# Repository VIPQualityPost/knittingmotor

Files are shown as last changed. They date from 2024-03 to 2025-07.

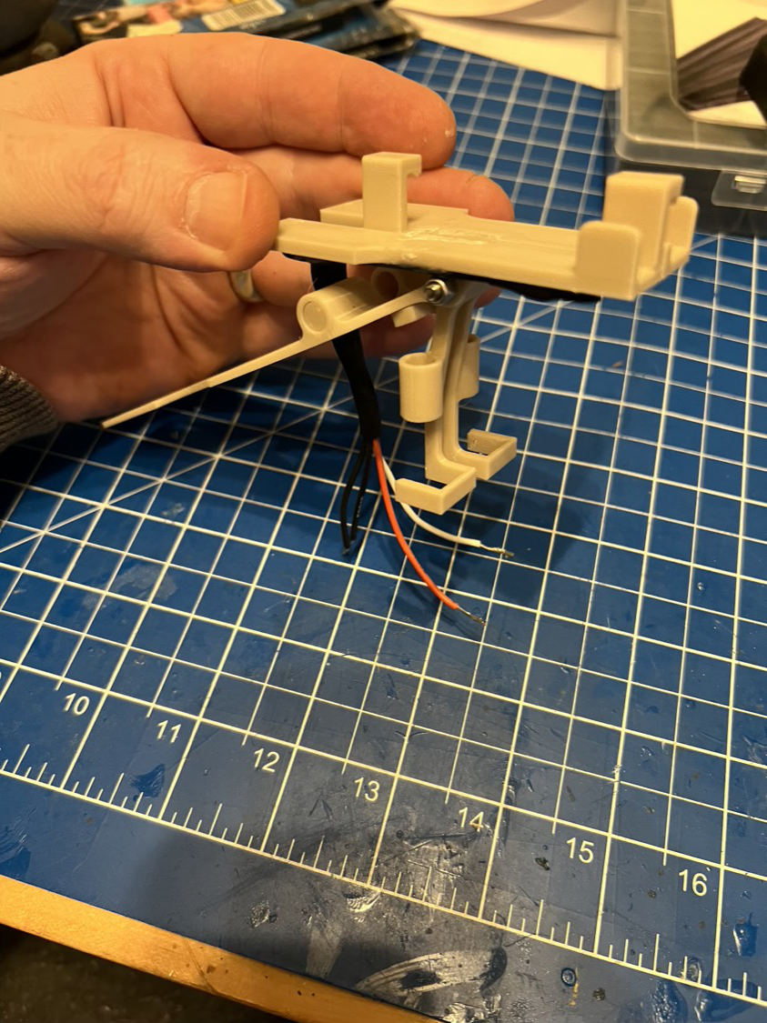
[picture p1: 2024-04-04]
docs/content/rl/pictures/yarn_sensor_build_4.jpg

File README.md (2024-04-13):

# OKM - Open Knitting Motor project
===================================

THIS PROJECT AND ITS DOCUMENTATION IS WORK IN PROGRESS - EVEN THOUGH THE ACTUAL MACHINE WORKS, THERE ARE STILL SOME DOCUMENTATIONAL PARTS MISSING, SO IT MIGHT NOT BE AS EASY TO FOLLOW EVERYTHING AS IT SHOULD!

This project intends to provide a knitting motor for the common Brother flat bed knitting machines. It is originally build for a Brother KH 830 knitting machine, but the parts can be customized easily, so that it can be used with different machines.

It provides currently the following features:

*Features:*
- manual knitting with simple row counter
- automatic knitting a pre-defined no. of rows
- foot pedal control (single row / continuous knitting)
- knitting of the whole bed or a subsection
- setup and row data saved between power on/off
- alarm song after pre-defined no. of rows done
- user definable speed setting

*Machine operation and safety features:*
- high resolution stepper motor driver
- electronic endstops and carriage transport overload protection
- mechanic (spring driven) carriage coupler (additionally to overload protection)
- yarn and knot sensor (optional)

Current documentation: https://pages.open-mind.space/knittingmotor

Firmware release overview: https://gitlab.open-mind.space/pages/knittingmotor/-/releases

Building this device is not for the faint-hearted, because you will have to solder, crimp connectors, even deal with mains connections (! PLEASE BE CAREFUL ! I AM NOT RESPONSIBLE IF SOMETHING GOES WRONG HERE !), building and uploading the firmware to the Arduino, and in the end, debug the whole thing if something does not work as expected.

So, if you are not familiar with doing things like this, please ask a friend with appropriate skills for help.

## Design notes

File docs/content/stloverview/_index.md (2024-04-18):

---
title: "STL overview"
date:  "2024-04-07"
weight: 40
---

------

{{< figure src="/knittingmotor/images/CAD_OKM.png" link="/knittingmotor/images/CAD_OKM.png" target="blank" title="(click to zoom)" height="60%" width="60%" >}}

------

This overview is just for informational purpose.

Download the current STL files or the combined 3MF from: [source files](https://gitlab.open-mind.space/pages/knittingmotor)

<br>

{{< gallery match="pictures/*" sortOrder="desc" rowHeight="150" margins="5" thumbnailResizeOptions="600x600 q90 Lanczos" showExif=true previewType="blur" embedPreview=true loadJQuery=true >}}

---

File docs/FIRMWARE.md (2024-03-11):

# Open Knitting Motor - Firmware

The project is being developed under Visual Studio Code with the PlatformIO plugin. If you use the same IDE, you should not have any problems compiling and flashing the firmware to the Arduino, as all necessary external libraries will be configured via `platformio.ini`.

## Choosing the right firmware branch

The firmware comes in two different versions:
- Arduino R3 support (`master` branch)
- Arduino R4 support (`r4wifiv2` branch)

Choose the firmware branch according the Arduino UNO type you are using. The branches are not cross-compatible, so you cannot simply compile the `master` branch and use it wth the Arduino R4. This simply won't work.

## Multi-language support
The firmware comes in two different languages at the moment, German or English. You can change this in `platform.io`via the `build_flags` parameter:

- -D LANG_DE (for German) <br>
or <br>
- -D LANG_EN (for English)

I did not build a live language option into the firmware, as it won't happen too often that a user wants to change the language while using the machine. So, the language will be compiled directly into the firmware.

If you want to add another language, see `Lang.h` for how it is done.

## Serial debug options
If you want to enable some more (serial) DEBUG options, you can setup some additional `build_flags` in platformio.ini:

- -D DEBUG: will enable general debug output, has to be defined always for debuggin
- -D DEBUG_APPMODE: will generate debug messages regarding the firmware operation itself
- -D DEBUG_POSITION: will generate additional information regarding the stepper and encoder operation

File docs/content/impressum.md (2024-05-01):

---
title: "Impressum/Imprint"
date: 2024-04-05
lastmod: 2024-04-05
publishdate: 2024-04-05
description: ""
weight: 1000
---

<div class='impressum'><h1>Impressum</h1><p>Angaben gemäß § 5 TMG</p><p>Holger Pandel <br> 
Am Steinbrink 15<br> 
47447 Moers <br> 
</p><p> <strong>Vertreten durch: </strong><br>
Holger Pandel<br>
</p><p><strong>Kontakt:</strong> <br>
Telefon: 02841-9393211<br>
E-Mail: <a href='mailto:holger.pandel@googlemail.com'>holger.pandel@googlemail.com</a></br></p><p><strong>Haftungsausschluss: </strong><br><br><strong>Haftung für Inhalte</strong><br><br>
Die Inhalte unserer Seiten wurden mit größter Sorgfalt erstellt. Für die Richtigkeit, Vollständigkeit und Aktualität der Inhalte können wir jedoch keine Gewähr übernehmen. Als Diensteanbieter sind wir gemäß § 7 Abs.1 TMG für eigene Inhalte auf diesen Seiten nach den allgemeinen Gesetzen verantwortlich. Nach §§ 8 bis 10 TMG sind wir als Diensteanbieter jedoch nicht verpflichtet, übermittelte oder gespeicherte fremde Informationen zu überwachen oder nach Umständen zu forschen, die auf eine rechtswidrige Tätigkeit hinweisen. Verpflichtungen zur Entfernung oder Sperrung der Nutzung von Informationen nach den allgemeinen Gesetzen bleiben hiervon unberührt. Eine diesbezügliche Haftung ist jedoch erst ab dem Zeitpunkt der Kenntnis einer konkreten Rechtsverletzung möglich. Bei Bekanntwerden von entsprechenden Rechtsverletzungen werden wir diese Inhalte umgehend entfernen.<br><br><strong>Haftung für Links</strong><br><br>
Unser Angebot enthält Links zu externen Webseiten Dritter, auf deren Inhalte wir keinen Einfluss haben. Deshalb können wir für diese fremden Inhalte auch keine Gewähr übernehmen. Für die Inhalte der verlinkten Seiten ist stets der jeweilige Anbieter oder Betreiber der Seiten verantwortlich. Die verlinkten Seiten wurden zum Zeitpunkt der Verlinkung auf mögliche Rechtsverstöße überprüft. Rechtswidrige Inhalte waren zum Zeitpunkt der Verlinkung nicht erkennbar. Eine permanente inhaltliche Kontrolle der verlinkten Seiten ist jedoch ohne konkrete Anhaltspunkte einer Rechtsverletzung nicht zumutbar. Bei Bekanntwerden von Rechtsverletzungen werden wir derartige Links umgehend entfernen.<br><br><strong>Urheberrecht</strong><br><br>
Die durch die Seitenbetreiber erstellten Inhalte und Werke auf diesen Seiten unterliegen dem deutschen Urheberrecht. Die Vervielfältigung, Bearbeitung, Verbreitung und jede Art der Verwertung außerhalb der Grenzen des Urheberrechtes bedürfen der schriftlichen Zustimmung des jeweiligen Autors bzw. Erstellers. Downloads und Kopien dieser Seite sind nur für den privaten, nicht kommerziellen Gebrauch gestattet. Soweit die Inhalte auf dieser Seite nicht vom Betreiber erstellt wurden, werden die Urheberrechte Dritter beachtet. Insbesondere werden Inhalte Dritter als solche gekennzeichnet. Sollten Sie trotzdem auf eine Urheberrechtsverletzung aufmerksam werden, bitten wir um einen entsprechenden Hinweis. Bei Bekanntwerden von Rechtsverletzungen werden wir derartige Inhalte umgehend entfernen.<br><br><strong>Datenschutz</strong><br><br>
Die Nutzung unserer Webseite ist in der Regel ohne Angabe personenbezogener Daten möglich. Soweit auf unseren Seiten personenbezogene Daten (beispielsweise Name, Anschrift oder eMail-Adressen) erhoben werden, erfolgt dies, soweit möglich, stets auf freiwilliger Basis. Diese Daten werden ohne Ihre ausdrückliche Zustimmung nicht an Dritte weitergegeben. <br>
Wir weisen darauf hin, dass die Datenübertragung im Internet (z.B. bei der Kommunikation per E-Mail) Sicherheitslücken aufweisen kann. Ein lückenloser Schutz der Daten vor dem Zugriff durch Dritte ist nicht möglich. <br>
Der Nutzung von im Rahmen der Impressumspflicht veröffentlichten Kontaktdaten durch Dritte zur Übersendung von nicht ausdrücklich angeforderter Werbung und Informationsmaterialien wird hiermit ausdrücklich widersprochen. Die Betreiber der Seiten behalten sich ausdrücklich rechtliche Schritte im Falle der unverlangten Zusendung von Werbeinformationen, etwa durch Spam-Mails, vor.<br>
<br>
Impressum vom <a href="https://www.impressum-generator.de">Impressum Generator</a> der <a href="https://www.kanzlei-hasselbach.de/standorte/frankfurt/">Kanzlei Hasselbach, Frankfurt</a> </div>

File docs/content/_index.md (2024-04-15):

---
title: "_Index"
date: 2024-03-18T11:07:29+01:00
lastmod: 2024-03-18T11:07:29+01:00
publishdate: 2024-03-18T11:07:29+01:00
description: ""
weight: 10
---

Welcome to my

# Open Knitting Motor Project

------
| {{< figure src="/knittingmotor/images/CAD_OKM.png" link="/knittingmotor/images/CAD_OKM.png" target="blank" title="(click to zoom)" height="80%" width="80%" >}} | {{< figure src="/knittingmotor/images/CAD_OKM_back.png" link="/knittingmotor/images/CAD_OKM_back.png" target="blank" title="(click to zoom)" height="80%" width="80%" >}} |
| :---: | :---: |
------

Here you find every information you need to build and use your own custom flatbed knitting machine motor.

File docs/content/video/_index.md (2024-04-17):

---
title: "Introduction video"
date: "2024-04-12"
weight: 10
TableOfContents: false
---

The following video should give you a comprehensive introduction to my open knitting motor. There are more videos to come, especially those explaining the different features you can setup within the control box.

---
<br>
{{< youtube DNebWPWqzuI >}}

[Follow this link to the complete Youtube playlist with all videos regarding the system!](https://www.youtube.com/playlist?list=PLf4mh2tju_ITPJRGPDabReALq2cNbygUf)

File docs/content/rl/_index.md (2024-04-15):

---
title: "Pictures from the build"
date:  "2024-04-04"
weight: 30
---

---

{{< figure src="/knittingmotor/images/OKM_build_view.jpg" link="/knittingmotor/images/OKM_build_view.jpg" target="blank" title="(click to zoom)" height="60%" width="60%" >}}

---

## So, what do you think?

No worries, I can assure you, it is working as of now. Here you find a bunch of pictures I took during the build of the actual machine itself. I hope, you find them useful in the process of building your own motor.

<br>

{{< gallery match="pictures/*" sortOrder="desc" rowHeight="150" margins="5" thumbnailResizeOptions="600x600 q90 Lanczos" showExif=true previewType="blur" embedPreview=true loadJQuery=true >}}

---

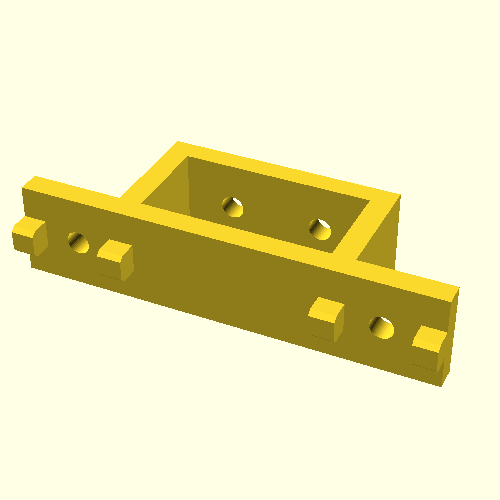
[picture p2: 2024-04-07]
docs/content/stloverview/pictures/frame_barclamp_(2x).stl.png

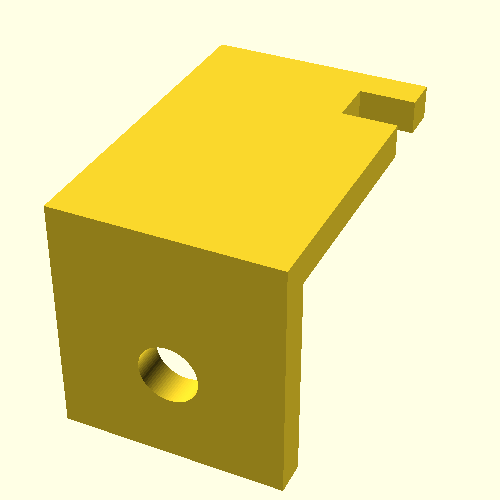
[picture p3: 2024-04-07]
docs/content/stloverview/pictures/frame_main_clamp_left.stl.png

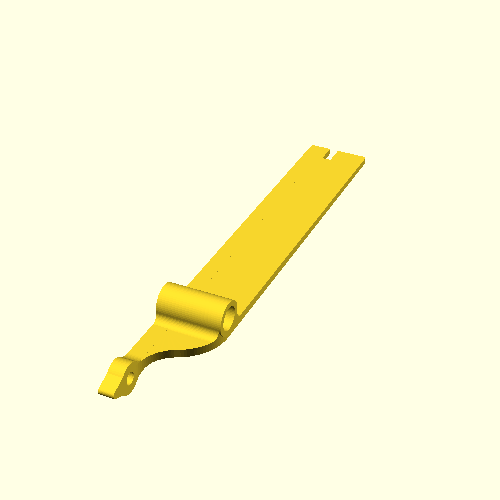
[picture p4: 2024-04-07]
docs/content/stloverview/pictures/yarn_sensor_knot_main_thread.stl.png

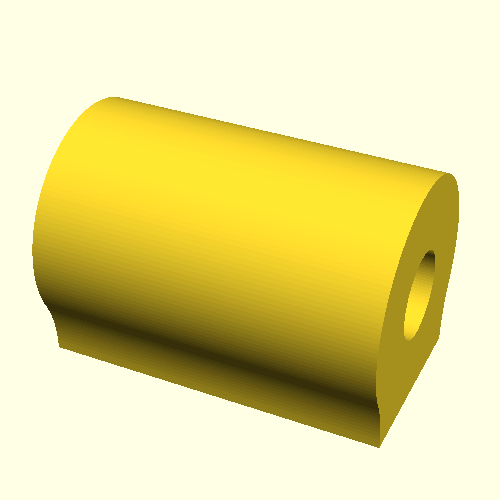
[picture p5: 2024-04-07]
docs/content/stloverview/pictures/belt_tensioner_pusher.stl.png

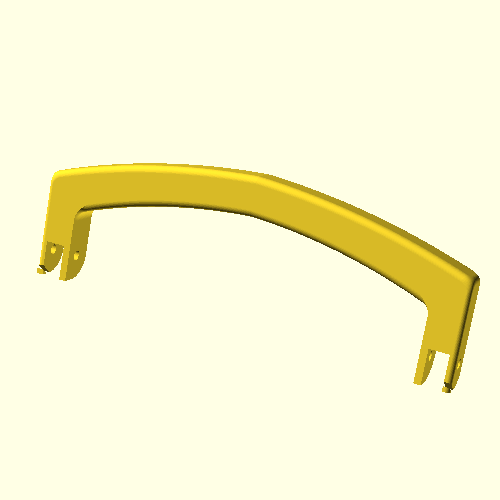
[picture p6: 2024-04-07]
docs/content/stloverview/pictures/carriage_handle_bar.stl.png

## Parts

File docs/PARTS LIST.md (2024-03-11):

# Open Knitting Motor - Parts list

This document hopefully lists all the needed parts to build the open knitting motor.

## 3D printed parts

Print all of the parts you find in the `Kitting machine motor.3mf`. I used 6 walls, with 35% infill at 0.2mm layer height and tree support where needed. If you have a Bambulab X1C printer, you should be able to use the 3MF file directly without any further modifications.

Regarding the housing, you have to choose between TB6600 and DM542T because of the stepper driver.

## V-Slot Extrusions and accessories

- 2020:
  - 1700mm (1x)
  - 1160mm (1x)

- 2040:
  - 250mm (2x)
  - 200mm (2x)

- corner brackets (8 minimum, more as you like)
- T-nuts (35 minimum)
- M5x8 T-nut pan head screws
- end caps for extrusions, if you like

## Electronics

- Arduino UNO R3 (R4 support since 0.4.6+78 in separate fw branch)
- DFRobot LCD Keypad shield
- LM2596 Step-down DC-DC Buck-Converter modul for 4-40V to 3,3-24V
- Passive buzzer module
- Optical rotary A/B encoder E38S6G5-600B-G24N
- DC power supply 24V 10A
- IEC320 / C14 power jack
- Nema 23 stepper motor type 23HS2430B [like this](https://www.sys-motor.com/show.aspx?id=165)
- Stepper driver alternatives (configured for 1600 steps):
    1. TB6600 stepper driver (works, but not recommended)
    2. DM542T (MUCH better, quieter, more precise, etc. etc.)
- 12V 2-pin Fan (40x40x10)
- (2x) Lerdge endstops [like this](https://shop.lerdge.com/products/mechanical-endstop-horizontal)
- (2x) small endstop switches (normally closed, footswitch+overload)
- (4x) reed contact 10mm (normally closed, yarn sensing)
- (2x) GX16 4-pin male+female plug connector (for stepper motor and encoder)
- (3x-4x) Stereo jack connector socket panel mount (for endstops, footswitch, (optional) overload and yarn sensor)
- (3x-4x) 3.5mm stereo TRS plug
- something to connect all GND and +5V lines together - I used Wago splicing connectors with levers, but everthing else with which you can connect multiple wires into one should work :D

## Mechanics

- (1x) Openbuild V-slot gantry for 2020 with 4 wheels, [like this](https://openbuildspartstore.com/v-slot-gantry-kit-20mm/)
- (1x) GT2 pulley 30T 8mm bore
- (1x) GT2 idler pulley with 5mm bore
- (5m) GT2 belt 6mm width
- (1x) (heatbed) compression spring (len 20 mm/0.79 inch, od 7.5 mm/0.3 inch, id 5 mm/0.2 inch, wire 1.2 mm)
- a whole bunch of M3, M4, M5 and M6 screws in different lengths
- about 500mm 0.8 piano wire

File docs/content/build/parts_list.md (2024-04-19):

---
title: "Parts list"
date:  "2024-03-18"
#menu:
#  main:
#      parent: Build your own!
weight: 10
TableOfContents: true
---

This document hopefully lists all the needed parts to build the open knitting motor.

## 3D printed parts

If you have a Bambulab X1C printer and  use BambuStudio as your preferred slicer, print all of the parts you find in the `Open knitting motor.3mf`without any further modifications. I positioned every item the same way I printed them myself. 

If you have to use the single STL files, then, as a rule of thumb, 

- use 6 walls
- with 35% infill at 0.2mm layer height
- tree support where needed.

Regarding the housing, you have to choose between TB6600 and DM542T because of the stepper driver.

For the foot switch, get the following part from its designer *flummer* directly via Printables:
Foot switch: https://www.printables.com/de/model/723123-foot-pedal-switch

## V-Slot Extrusions and accessories

- 2020:
  - 1700mm (1x, run bar)
  - 1160mm (1x, front rest bar)

- 2040:
  - 250mm (2x, mount post)
  - 200mm (2x, foot)

- [Openbuild V-slot gantry for 2020 with 4 wheels,](https://openbuildspartstore.com/v-slot-gantry-kit-20mm/)
- [corner brackets](https://openbuildspartstore.com/cast-corner-bracket/) (8 minimum, more as you like)
- T-nuts M5 (for frame connection, about 36, but it is handy two a some more)
- M5x8 T-nut pan head screws for the T-nuts
- M3 hammer nuts (for fixing endstops, etc.)
- end caps for extrusions (for esthetical reasons, if you like)

I cannot give you any advice where to buy your parts from, but for the extrusion, see the [Openbuilds Partstore](https://openbuildspartstore.com/) for reference.

## Electronics

I try to provide links to every part as an example, so that you can see what is meant exactly.

- [Arduino UNO R4 Wifi](https://store.arduino.cc/products/uno-r4-wifi) (DON'T use UNO R3, firmware does not support it anymore)
- [D1 Robot LCD Keypad shield](https://www.aliexpress.us/item/3256805923237105.html)<br>
  There are other  shields made by DFRobot, but they are slightly different and bigger. They won't fit into the keypad bezzle and also may react differently to the buttons attached, so try to find the exact same one made by D1 Robot.
- [LM2596 Step-down DC-DC Buck-Converter modul for 4-40V to 3,3-24V](https://www.amazon.de/gp/product/B08T1ZR6XG)
- [Passive(!) Arduino buzzer module](https://www.amazon.de/gp/product/B096ZWCG7F)
- [Optical rotary A/B encoder 600P/R rotary encoder](https://www.amazon.com/Signswise-Incremental-Optical-Encoder-Quadrature/dp/B085ZLCYS1)<br>
  Its technical no. is sometimes *LPD3806-600BM-G5-24C* or *E38S6G5-600B-G24N*.
- [DC power supply 24V 10A](https://www.amazon.de/gp/product/B0896XTJ14)
- [IEC320 / C14 power jack (pre-wired at best)](https://www.amazon.com/button-Adapter-Connector-Socket-MXRS/dp/B082ZFRV1B)
- [Nema 23 stepper motor type 23HS2430B](https://www.sys-motor.com/show.aspx?id=165)
- Stepper driver alternatives (configured for 1600 steps):
    1. [TB6600 stepper driver](https://www.amazon.com/Stepper-DC9-42V-Subdivision-Controller-MicroStepping/dp/B08SG7L54W) (works, but not recommended)
    2. [DM542T stepper driver](https://www.omc-stepperonline.com/search?search=dmt542t&description=true) (MUCH MUCH better, quieter, more precise, etc. etc.)
- [Noctua 12V 3-pin fan (40x40x10)](https://www.amazon.com/Noctua-Cooling-Blades-Bearing-NF-A4x10/dp/B009NQLT0M)
- [ZHIYU 1X3L fan controller](https://www.ebay.com/itm/404706261069)
- (2x) [Lerdge endstops ](https://shop.lerdge.com/products/mechanical-endstop-horizontal)
- (2x) [small endstop switches](https://www.amazon.de/gp/product/B07P85749W) (normally closed, footswitch+overload)
- (2x) [GPS-11B reed contact 10mm](https://www.ebay.com/itm/284819532789) (normally closed, yarn knot sensor)
- (2x) [GPS-14A reed contact 14mm](https://www.ebay.com/itm/284819532789) (normally open, yarn run out sensor)
- (4x) [neodymium magnet 6mm x 3mm](https://www.ebay.com/itm/305313785899) (for reed contacts used in yarn sensor)
- (2x) [GX16 4-pin male+female plug connector](https://www.ebay.com/itm/335215956016) (for stepper motor and encoder)
- (3x-5x) [Stereo jack connector socket panel mount](https://www.ebay.com/itm/385445764175) (two endstops, footswitch, (optional) overload and yarn sensor)
- (3x-5x) [3.5mm stereo TRS plug](https://www.amazon.com/Fancasee-Replacement-Connector-Headphone-Earphone/dp/B07Y8KGJKL)
- something to connect all GND and +5V lines together - I used Wago splicing connectors with levers, but everthing else with which you can connect multiple wires into one should work :D
- A bunch of wires
    1. 24 AWG (multi-color): Arduino, rotary encoder, switches, reed contacts
    2. 18-20 AWG: power supply to step down, stepper+driver phase connections (better use 4 core cable with shielding)

## Additional mechanical parts

- **(2x) [original ribber clamps for KR830/850](https://theknittingcloset.com/products/knitting-machine-ribber-parts), you cannot use the whole setup without them**
- (1x) [GT2 pulley 30T 8mm bore](https://www.amazon.com/Saipe-Synchronous-Teeth-Bore-8mm/dp/B09JS7CZNM)
- (1x) [GT2 idler pulley 5mm bore](https://www.amazon.com/3Dman-Toothless-Aluminum-Timing-Printer/dp/B07RV2T54M)
- (5m) [GT2 belt 6mm width](https://www.amazon.com/Timing-Printer-FYSETC-Fiberglass-Reinforced/dp/B07BRKZGMS)
- (1x)  compression spring (len 20 mm/0.79 inch, od 7.5 mm/0.3 inch, id 5 mm/0.2 inch, wire 1.2 mm) - i. e. for 3D printer heatbed
- a whole bunch of M3, M4, M5 and M6 screws and (nylon lock) nuts in different lengths
- about 500mm 0.8 piano wire

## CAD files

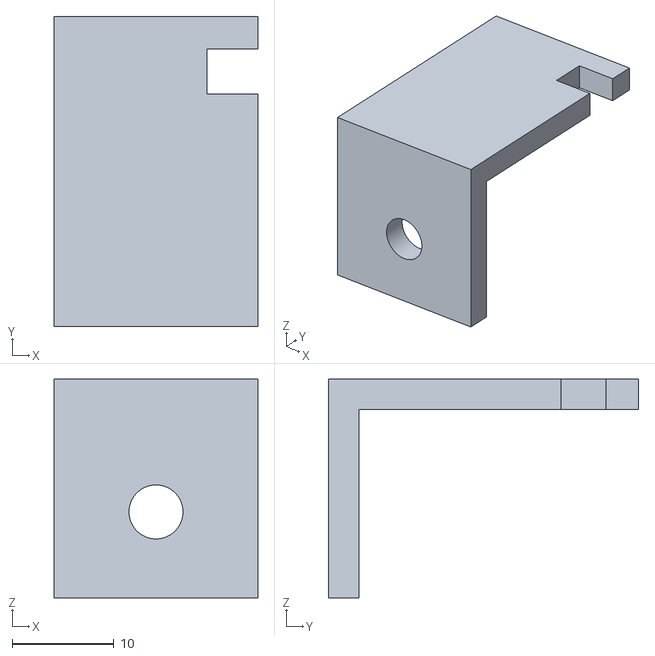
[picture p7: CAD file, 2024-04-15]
STL/frame_main_clamp_left.stl
20.0 x 30.5 x 21.5

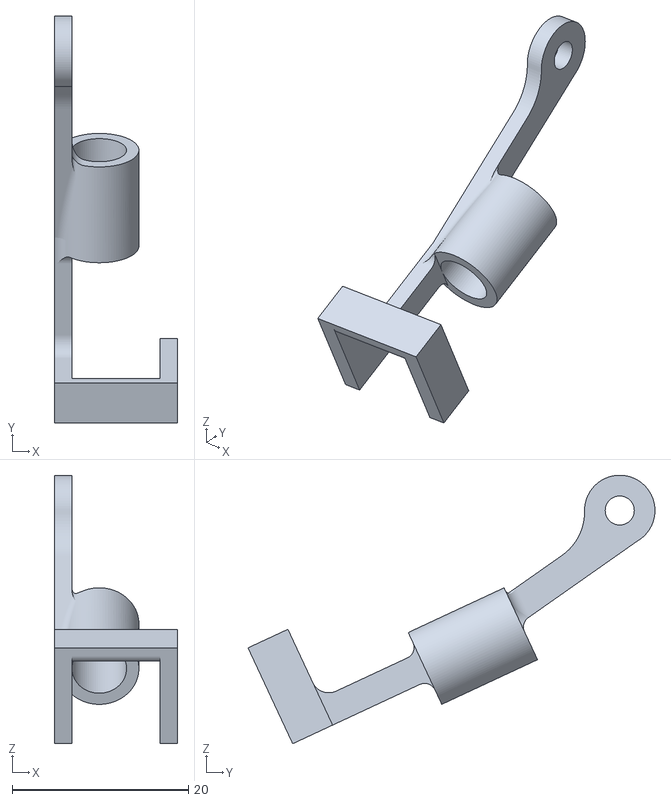
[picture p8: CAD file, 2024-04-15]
STL/yarn_sensor_main_thread.stl
14.0 x 46.2 x 30.5

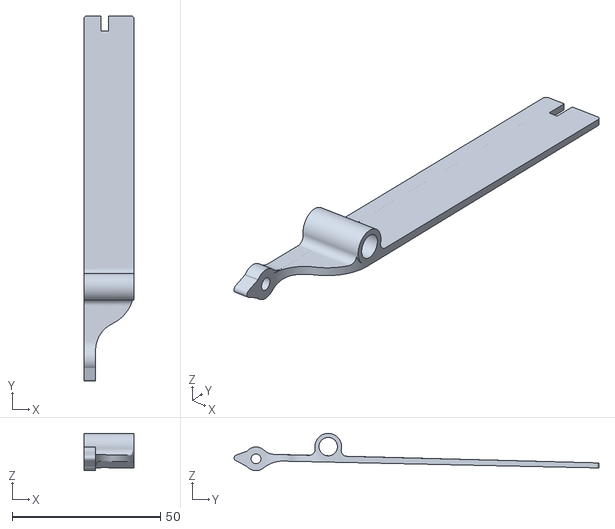
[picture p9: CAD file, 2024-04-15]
STL/yarn_sensor_knot_main_thread.stl
17.0 x 123.1 x 12.6

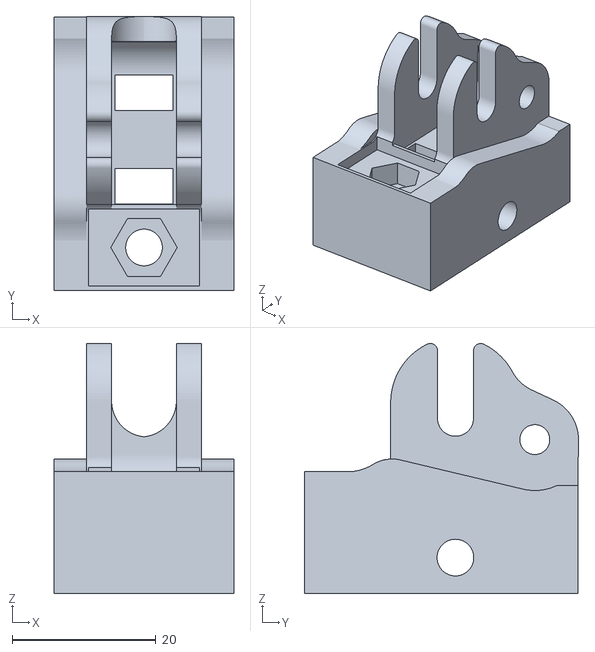
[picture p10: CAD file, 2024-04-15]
STL/belt_tensioner_main_body.stl
25.0 x 38.1 x 34.8

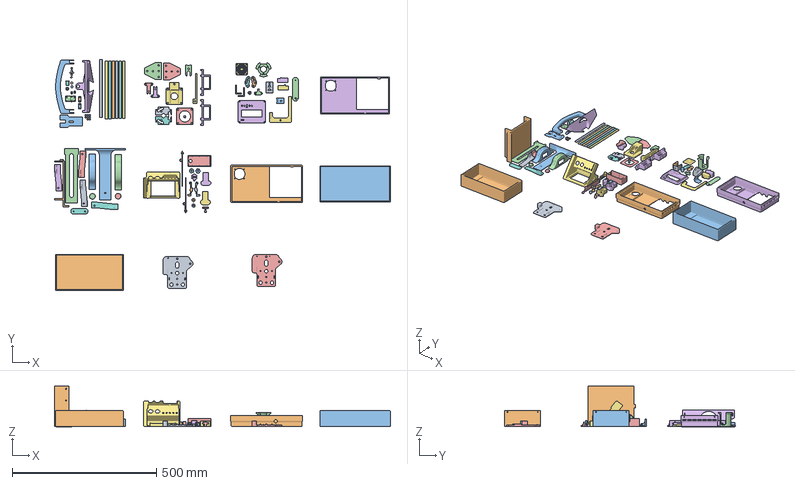
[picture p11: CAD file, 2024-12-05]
Open knitting motor.3mf
1165.1 x 800.2 x 141.9 mm
Mover plate.stl
lower housing (TB6600).stl
yarn sensor base.stl
stabilizer rod fixer.stl
yarn knot sensor main thread.stl
barclamp.stl x 2
yarn knot sensor second thread.stl
stabilizer short arm.stl
yarn sensor second thread.stl
yarn sensor main thread.stl
stabilizer mount.stl
rotary encoder bracket bridge.stl
yarn sensor base screw mount.stl
carrier adapter.stl
spring lever.stl
carrier bolt.stl
spring bolt spacer.stl
spring presser.stl x 2
carrier handle bar.stl
t-joining plate.stl x 2
Nema 23 2020 Extrusion Bracket.stl
Idler support tube.stl
main clamp right.stl
main clamp left.stl
belt slider.stl x 2
motor spacer.stl
upper housing part 1 (TB6600).stl
upper housing part 2.stl
LCD Keypad Pushbutton v3.stl x 6
LCD keypad bezzle.stl
Fan grill v2.stl
rotary encoder bracket base right.stl
rotary encoder bracket base left.stl
Flexible Shaft Coupler Sleeve 6mm.stl
Flexible Shaft Coupler Sleeve 8mm.stl
Flexible Shaft Coupler Body.stl
vertical stiffner right.stl x 2
vertical stiffner left.stl x 2
mover endstop bracket.stl
control box table.stl
control box table foot part 2.stl
control box table foot part1.stl
endstop mount.stl x 2
VslotCover_Cust_50mm.stl x 7
GT2_Clip_7_mm.stl x 2
Belt holder right.stl
Belt holder left.stl
right arm
main body
left arm
pusher
overload sensor mount.stl
pulley lid.stl
endstop lid.stl x 2
M5_std_screw_knob.stl x 2
M3_std_screw_knob.stl x 2
GX16 blind plug.stl x 2
cable spring holder.stl
upper housing part 1 (DMT542T).stl
lower housing (DMT542T).stl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

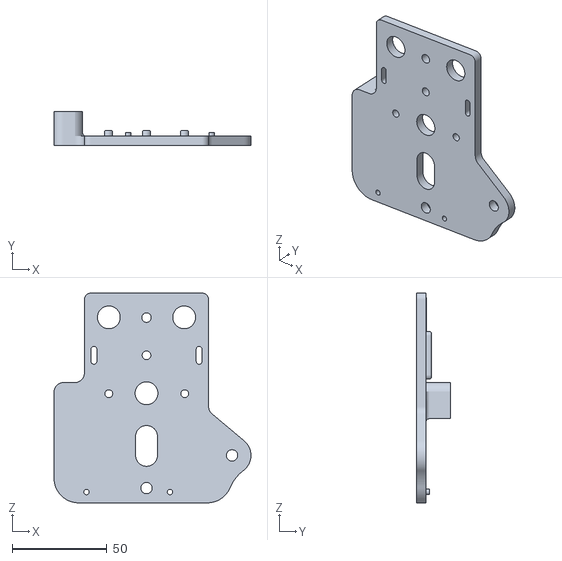
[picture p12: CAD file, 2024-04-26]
STL/mover_plate_v2.stl
103.8 x 18.0 x 110.5

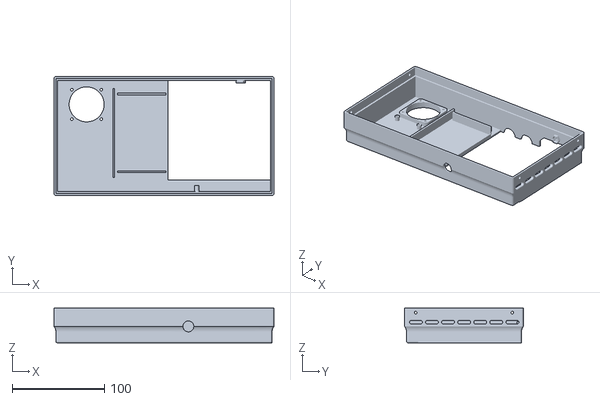
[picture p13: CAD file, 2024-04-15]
STL/control_box_upper_housing_part_1_(TB6600).stl
239.0 x 129.0 x 38.0

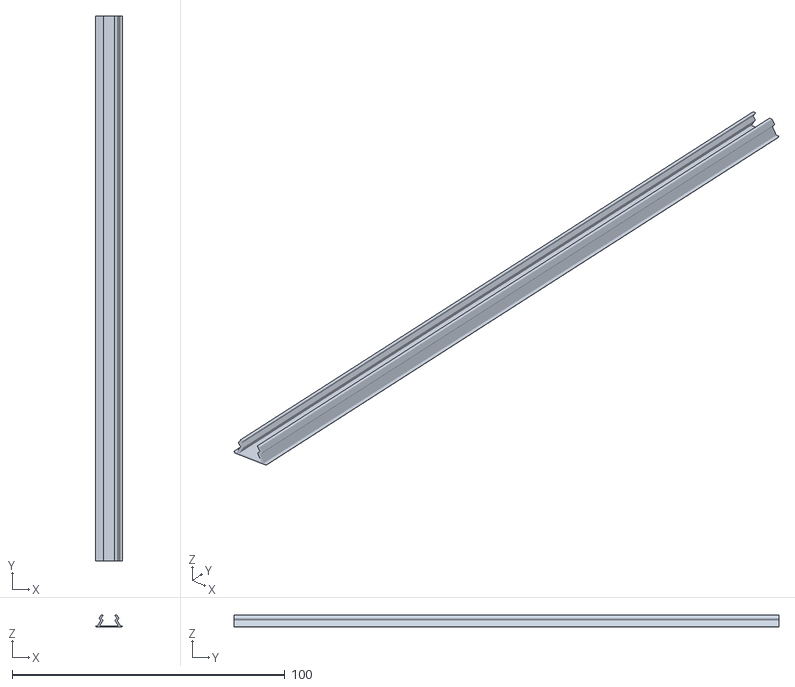
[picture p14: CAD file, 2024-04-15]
STL/frame_v-slot_cover_50mm_(about_7x).stl
10.0 x 200.0 x 4.40

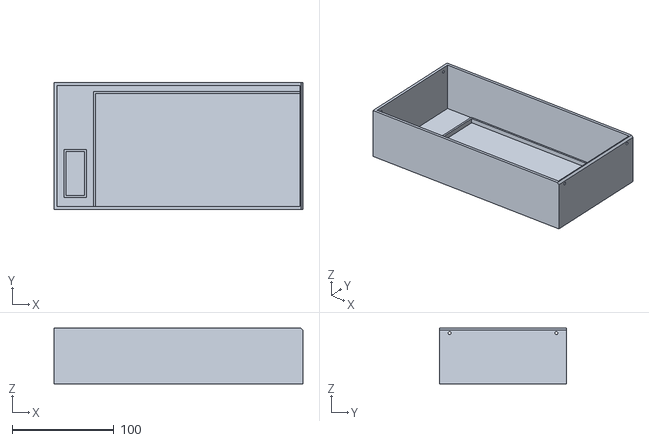
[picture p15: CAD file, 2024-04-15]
STL/control_box_lower_housing_(DMT542T).stl
245.0 x 125.0 x 55.0

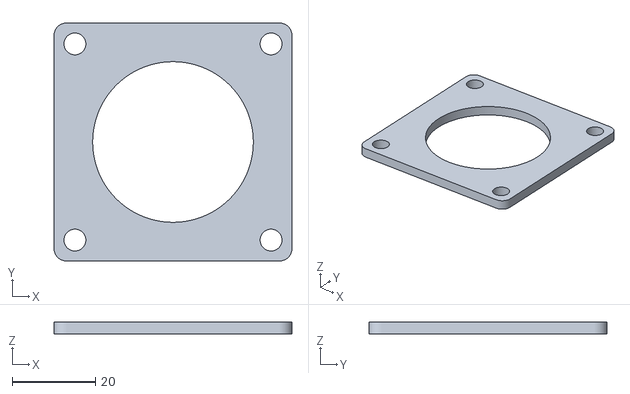
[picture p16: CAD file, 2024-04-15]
STL/frame_stepper_mount_motor_spacer.stl
57.2 x 57.2 x 3.00

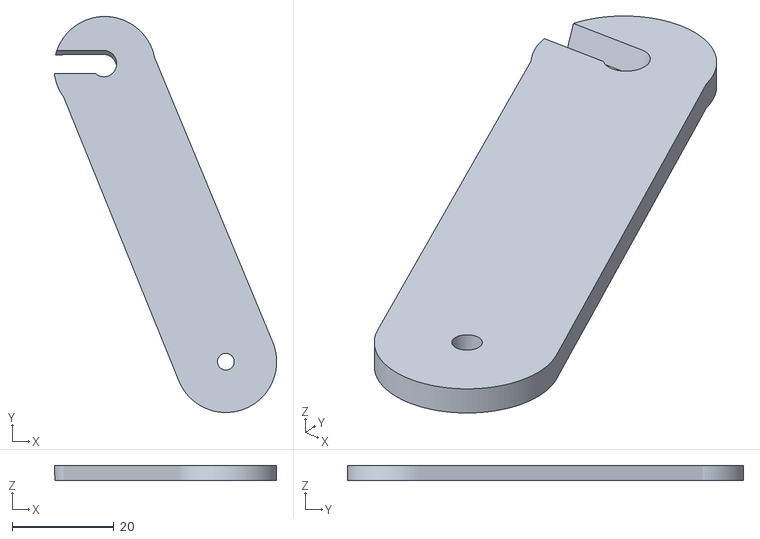
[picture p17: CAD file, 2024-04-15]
STL/yarn_mast_stabilizer_rod_fixer.stl
43.8 x 77.9 x 3.00

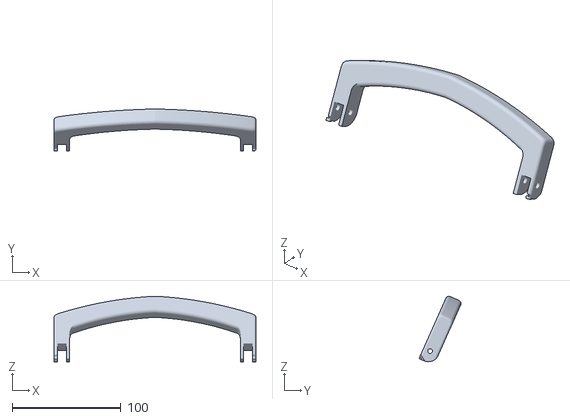
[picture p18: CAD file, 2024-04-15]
STL/carriage_handle_bar.stl
186.2 x 38.8 x 60.4

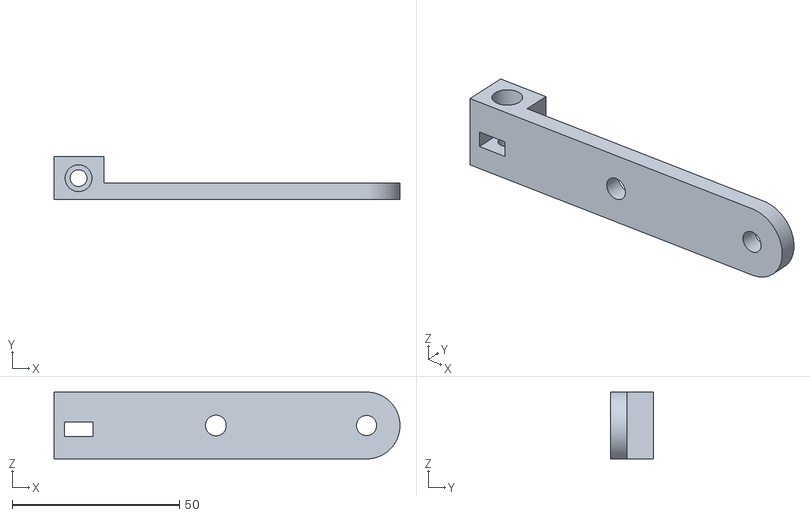
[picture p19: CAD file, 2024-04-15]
STL/mover_spring_lever.stl
103.5 x 13.0 x 20.0

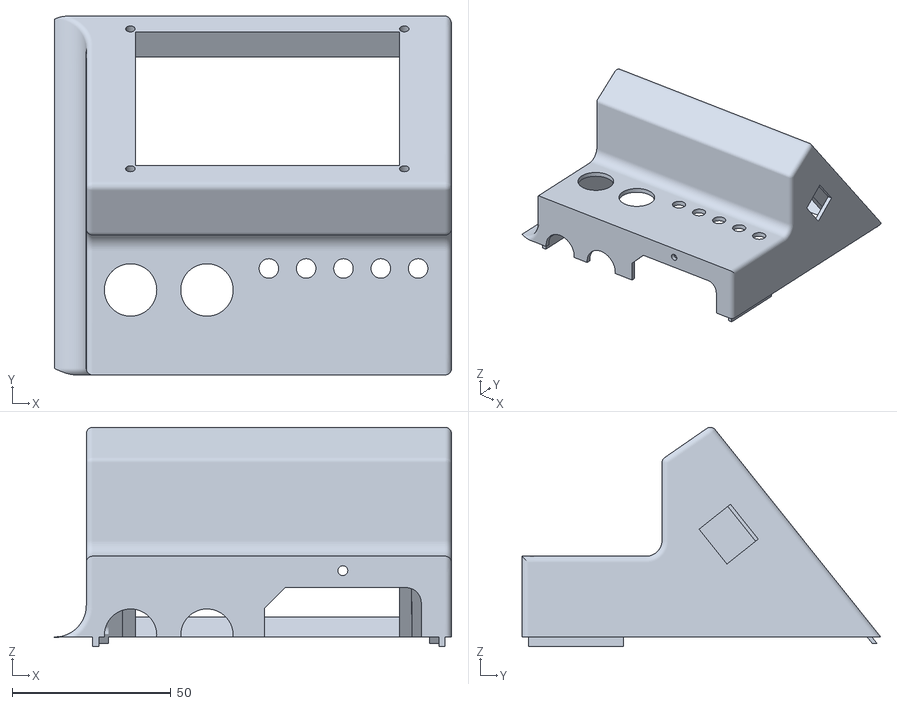
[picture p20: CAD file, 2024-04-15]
STL/control_box_upper_housing_part_2.stl
125.0 x 113.0 x 69.1

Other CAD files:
STL/frame_main_clamp_right.stl
STL/yarn_sensor_base.stl
STL/belt_tensioner_arm_(2x).stl
STL/frame_barclamp_(2x).stl
STL/GT2_clip_(2x).stl
STL/M3_std_screw_knob_(2x).stl
STL/M5_std_screw_knob_(2x).stl
STL/belt_tensioner_pusher.stl
STL/carriage_adapter_plate.stl
STL/carriage_bolt.stl
STL/control_box_GX16_blind_plug_(if_needed).stl
STL/control_box_fan_grill.stl
STL/control_box_lcd_keypad_bezzle.stl
STL/control_box_lower_housing_(TB6600).stl
STL/control_box_pushbutton_(6x).stl
STL/control_box_table.stl
STL/control_box_table_foot_part_1.stl
STL/control_box_table_foot_part_2.stl
STL/control_box_upper_housing_part_1_(DMT542T).stl
STL/endstop_lid_(2x).stl
STL/endstop_mount_(2x).stl
STL/frame_T-joining_plate_(2x).stl
STL/frame_belt_slider_(2x).stl
STL/frame_stepper_mount.stl
STL/frame_vertical_stiffner_left_(2x).stl
STL/frame_vertical_stiffner_right_(2x).stl
STL/mover_belt_holder_left.stl
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

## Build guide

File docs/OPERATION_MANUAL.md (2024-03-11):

# Open Knitting Motor - Operation manual

## 1. Firmware pre-build configuration

Under normal circumstances you should use my pre-defined pin assignments, but in case you want to change something, you will have to adopt your changes before compiling the firmware. 
Open include/HardwareConfig.h and make all necessary changes.

<u>*Please only change any of the hardware parameters, like stepper and encoder resolution, if you exactly know what you are doing.*</u>

## 2. System startup

After powering on the control box, you will have to reset (aka homing) the knitting carriage once by pressing the `SELECT` button.

*Please make sure that during homing:<br>
- no needles are in working position or<br>
- that both PART buttons on the carriage are pressed and needles are in E position<br>
- simply disengage the carriage from the mover plate. After homing, the carriage will return to the zero position on the right and the motor is ready to knit.*

**(It can happen, that the carriage activates the zero position endstop when it returned right after homing. Simply ignore this error message and clear it by pressing the `SELECT` button.)**

To start knitting a single row right away, all you have to do is to just hit the foot pedal and the motor should start transporting the carriage one complete row. After the row has finished the carriage will knit in the opposite direction, if you hit the pedal again.

*You find knitting single rows to be too tedious? Me too...*<br>
No problem. If you want the motor to continuously knit a decent amount of rows, you simply setup the control box in `auto` mode (which is by default), enter a defined no. of rows and start the continuous knitting process via the buttons on the control box, or with the foot pedal, if it is configured for continuous knittin. See part 3. of the manual on how to do this.

***
*There is variant regarding continuous knitting:*

If you simply want the motor to continuously knit, regardless of the row count, you can set the control box into `manual` mode. Then you can start continuous knitting and the control box will only count the rows knitted so far, but will not stop on its own.
***

If, for whatever reason, you encounter any problems (some unknown error, menu not responding, whatever) and want to start over, simply press the `RESET`button. The button will restart the control box and you are good to go. You will not loose the row count, if your box is in `auto` mode.(I.e. menu not responding *can* happen after one of the safety sensors was engaged.)

## 3. Daily usage, the menu system and important parameters

**Needle bed position naming convention**

			                                       needle bed
			      100 ---------------------------------0---------------------------------100
			       |                  |                |                 |                |
			    max position          |                |                 |          zero position
			                          |           mid position           |
			                    left boundary                        right boundary

### General menu handling

Press and hold the `UP` button to open the menu of the control box.

- Scroll through the menu with `UP` and `DOWN` buttons
- If submenus are available, a small arrow on the left or right of the menu item will appear. Now change the menu depth with `RIGHT` (descend) or `SELECT` (ascend)
- To edit a configuration value press `SELECT` -> a small arrow in front of the value will appear
- Change values with `UP` or `DOWN` button
- Finish editing a value by pressing `SELECT` again<br>
You can use the `Back` menu options to change the submenu one level up and the `Exit` menu command to exit the menu completely. Alternatively, you can simply wait 5 seconds, and the main menu will close. Hold in mind that the menu won't close as long as you are editing a parameter, like row count, motor speed, etc..

### Main daily usage parameters and handling

- Set row count (will be saved and reloaded)<br>
  Can be set between 1 and 999 rows. The meaning of "row count" is different between operation modes:<br>
  `auto` mode: Setup a number of rows to knit<br>
  `manual` mode: Correct the no. of rows knitted here to reflect any manual interactions which the control box can not account for on its own

- Boundaries (Left / Right boundary)<br>
  If you don't want to always knit the whole needle bed from left to right but rather a subsection in the middle to save time, you can set a left and right boundary for the carriage. <br><br>
  If you press `SELECT`to edit one of the boundary options the carriage will behave as follow: <br>
  1. *go to the middle of the needle bed, if no boundary has been set before*<br>
  2. *return to the last saved position* <br>

  You can then move the carriage left and right with the corresponding `LEFT` or `RIGHT` button on the control box and the new position will be saved. A short press will move the carriage a very short amount, press and hold the button for a bigger step.<br><br>
  Beware, that you can only set the left boundary further to the left of the middle of the bed, and it is the opposite with the right boundary. They can not be cross-set aka left boundary on the right and right boundary on the left.<br><br>

The boundaries don't have to be symmetrically aligned, but always have to be placed around the 0 needle position (middle of the bed).

**Carriage behaviour when you start knitting with boundaries:**

If the carriage is on the zero position, it will knit to the left boundary. Is the carriage on the max position, it will knit to the right boundary. Every further row will then be knitted between these two boundaries.

#### Manual carriage movement

If for some reason you want to bring the carriage over to the max or zero position regardless of the boundaries set, press and hold the `LEFT` or `RIGHT` button and the carriage will start to move in this direction, until the endpoint is reached.

Normally, boundary values are saved. If there are any problems with the carriage endstop positions when you turn the power on and after the first calibration routine (homing), the boundary values will be automatically set to 0 and you have to dial them in again.

<u>*BEWARE: Make sure no needles are engaged while setting the boundaries!*</u>

#### The yarn sensor and its activation

In case your system is equipped with a yarn sensor, the control box is able to detect, if the yarn runs out or if there is a knot in the yarn, for main and secondary color. You can activate the sensor for both colors independently, but runout and knot sensing will always be activated together per side.

So, if you activate main yarn sensor, it will automatically watch for yarn runout *and* knots in the yarn at the same time.

If the yarn sensor is activated during knitting, the following will happen:
- you get a message on screen, which you have to acknowledge by pressing `SELECT`
- the display will show an extra symbol `E` (see below for symbol description)
- the row counter will not be decreased (`auto` mode) or increased (`manual` mode) if you begin to knit again
- if you restart knitting, single row or continuous, the current row direction will be continued (!)

## 4. Configuration settings

To change any of the following parameters, open the control box menu and go to `Settings`.

- Operation mode (default: `auto`)<br>
  `auto`: Automatic knitting according to the given row count, machine will stop when all rows are done. Continuous knitting can only be started, if a positive row count is set.
  Knitting single rows is always possible via foot switch or `LEFT` and `RIGHT` buttons.<br>
  `manual`: The machine will only count the rows knitted.

  *Changing this configuration parameter will automatically clear the row count value and set it to 0!*

- Foot pedal mode (default: `single`)<br>
  `single`:     The foot switch will start knitting one row.<br>
  `continuous`: The foot switch will start continuous knitting. Hit the foot switch again to stop continuous knitting after the current row is done.

- Carriage speed (default: `80`)<br>
  You can raise and lower the carriage speed with a certain range. Please be careful and only raise the value in small steps and try again until it works as desired.

- Yarn sensor main (default: `off`)<br>
  Activate or deactivate, if the control box should check for messages from the main (color) yarn sensor.
  If you don't use one, set to `off`.<br>
  ***Changing this parameter requires a manual `REBOOT` of the control box.***

- Yarn sensor sec (default: `off`)<br>
  Activate or deactivate, if the control box should check for messages from the secondary (color) yarn sensor.
  If you don't use one, set to `off`.<br>
  ***Changing this parameter requires a manual `REBOOT` of the control box.***

- Overload sensor (default: `off`)<br>
  Activate or deactivate, if the control box should check for messages from the overload sensor.
  If you don't use one, set it to `off`.<br>
  ***Changing this parameter requires a manual `REBOOT` of the control box.***

- Direction arrow (default: `on`)<br>
  During knitting you will be presented with a small combination of symbols on the lower right side of the display right next to the current row count, showing you the knitting direction, if continuous knitting is active and if boundaries are set.
  If you set this option to `show`, the symbol combination will be kept on screen even after the carriage has stopped.
  If you set this to `hide`, the symbols will only be visible as long as the carriage is running.

  *Possible symbols:*<br>

      <-  -> : running direction of the carriage
      C      : continuous knitting active
      E      : shown, if the yarn sensor was activated in current row
      [    ] : boundaries set

  Examples:<br>
  - `[C->]`: last row was knitted to the right between boundaries and continuous knitting is on
  - `<-`   : last row was knitted to the left
  - `[E]`  : during last row between boundaries, the yarn sensor was activated

- Button beep (default: `on`)<br>
  If your control box is equipped with a buzzer, you can turn beeps on button press on or off.

- Alarm tune (default: `Entertainer`)<br>
  If you are in `auto` mode and have a buzzer installed, an alarm song will be played to show that everything finished.
  Choose the one you like the most.

- LCD backlight (default: `100%`)<br>
  If your LCD display is too bright for you, you can adjust the brightness between 33%, 66% and 100%.

## 5. Button usage on main screen

**Control box - button naming convention**

                                      UP
                                      |
                     SELECT -- LEFT --|-- RIGHT -- REBOOT
                                      |
                                      DOWN

| Button | Press duration | Function |
| :--- | :----: | :--- |
| `SELECT` | short press | after power on, start homing |
| `SELECT` | press and hold | start continuous knitting |
| `LEFT` | short press | move carriage a short way (about two needles) to the left |
| `LEFT` | press and hold | move carriage to its max position (ignores boundaries) |
| `UP` | press and hold | open menu |
| `DOWN` | short press | stop continuous knitting after current row<br><br>*(Due to the underlying system, it *can* sometimes last up to two rows <br>of knitting until the carriage stops.<br>But, normally it stops after the current row has finished.)* |
| `DOWN` | press and hold | zero values "Rows to knit" / "Knitted rows" |
| `RIGHT`  | short press | move carriage a short way (about two needles) to the right |
| `RIGHT`  | press and hold | move carriage to its zero position (ignores boundaries) |

## 6. Special menu items:

You find some additional, less important options in the menu:

- Boundaries / Clear boundaries<br>
  Reset boundary values to 0

- Tools / Home carriage<br>
  Tools / Move to (start/middle/end)
  Home carriage starts the self-calibration routine again you are faced with when you power on the control box.
  This can be necessary if there was a failure with the stepper motor, or after the coupler between the carriage mover and the carriage itself has been disconnected because of a blockage of the carriage.

  The `Move to...` options are only there for convenience and will behave exactly the same as the display buttons, although you can only move the carriage to the middle of the bed from here.

- Info<br>
  Will show the current firmware version.

- Reset all<br>
  Resets all firmware parameters to default. Please restart control box afterwards via the `REBOOT` button.

## 7. Troubleshooting

| Error message | Description | Solution |
| :---- | :----- | :----- |
| HIT 1 - MAX | Endstop in maximum position was activated | press `SELECT` to clear, re-home carriage |
| HIT 2 - HOME  | Endstop in zero position was activated | press `SELECT` to clear, re-home carriage |
| YARN 3 - MAIN | Yarn sensor main color activated | check, if knot in yarn or run out |
| YARN 4 - SEC  | Yarn sensor secondary color activated | check, if knot in yarn or run out |
| ERR 1 - FOOT  | No foot switch attached | attach foot switch |
| ERR 2 - OVRL  | Overload sensor activated | clear blockage or carrier, re-home carriage |

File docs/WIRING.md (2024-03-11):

# Open Knitting Motor - Wiring

## How to wire all parts?

I try to describe how I wired everything together the best I can. Sorry, no schematic available, but it should not be too complicated.

## PIN defaults

See `HardwareConfig.h` for the pin assignment defaults.

The minimum sensor (aka switch) pins you have to use are:
- home endstop
- max endstop
- foot switch

*Regarding yarn sensor / overload sensor pins:
You HAVE to assign valid pin numbers, even though you do not have to use the sensors as of the current firmware implementation.*

## External connectors

    GX16 4pin                   : stepper motor connection
    GX16 4pin                   : rotary encoder
    Stereo plug (GND + Tip)     : endstop max (left side of needle bed)
    Stereo plug (GND + Tip)     : endstop zero (right side of needle bed)
    Stereo plug (GND + Tip)     : foot switch
    Stereo plug (GND + Tip)     : overload sensor
    Stereo plug (GND, Ring, Tip): yarn sensor (main+secondary)

### PIN assignment
If you want to change the pin assignment to the Arduino for any reason, you will have to change the associated values in `include\HardwareConfig.h` and recompile the firmware.

## Common connection rails

### GND connection rail

    Arduino / LCD Shield
    all switches
    rotary encoder
    passive buzzer

### VIN (+5V) connection rail

    rotary encoder
    TB6600/DM542T Ena+
    TB6600/DM542T Dir+
    TB6600/DM542T Pul+
    passive buzzer

## Power supply

    24V volt to TB6600/DM542T
    24V volt to LM2596 Buck (In)

**Set Buck converter to 9 Volt.**

## Buck converter

    GND (Out): Arduino/LCD Shield GND
    GND (Out): Fan
    7V+ (Out): Arduino/LCD Shield VIN
    7V+ (Out): Fan

## Arduino + LCD Keypad Shield

Simply plug them together ;-)

Because of the design of the upper housing, you will have to solder wire connections and plugs to all available connectors on the LCD Keypad Shield, which are (D0-D3,D11-D13,A1-A5).

## LCD Keypad Shield

    D0:  passive buzzer
    D1:  overload sensor (normally closed)
    D2:  Rotary Encoder A
    D3:  Rotary Encoder B
    D11: TB6600/DM542T Pul-
    D12: TB6600/DM542T Dir-
    D13: TB6600/DM542T Ena-

    A1:  yarn sensor secondary (normally closed)
    A2:  yarn sensor main (normally closed)
    A3:  footswitch   (normally closed)
    A4:  endstop max  (normally closed)
    A5:  endstop zero (normally closed)

## TB6600 / DM542T

Use a GX16 connector.

(Only outgoing connections described, see VIN rail and LCD Keypad Shield for the rest of the connections.)

A+ / A- / B+ / B-: to stepper motor via GX16 connector

*Hint:<br>
To find out, which cables belong to which phase, simply hold two wires together and try to turn the motor by hand. If you feel quite a lot of resistance while the cables are held together, you found a phase ;-)*

After you hooked up the motor, you will have to check, if your wiring leads to the correct turning direction of the stepper. As a hint, if you mount the GT2 pulley to the motor and look right at it, the motor has to turn CCW when moving the carrier to the zero (right) position and CW to the max (left).

If the motor turns the opposite way, then simply rewire the cables on motor connector on the driver the other way around.

See this as example for rewiring the direction:

    A+: white    -> becomes   A+: green
    A-: blue     -> becomes   A-: brown
    B+: brown    -> becomes   B+: blue
    B-: green    -> becomes   B-: white

Regarding DM542T: make sure that the control voltage switch on top is set to 5V, or nothing will happen - don't ask how I know...

## Rotary enoder

Use a GX16 connector.

    GND  : Arduino GND **(!IMPORTANT!)**
    5V   : Arduino 5V (you have to make sure, that your Arduino
           DOES deliver real 5V, not 4.98V or something **(!IMPORTANT!)**
    GREEN: D2
    WHITE: D3

## Endstops and sensor pins

Use the stereo connectors.

See description under **LCD Keypad Shield** to find out where every switch has to be connected to. They are all tied to GND.

Only the yarn sensor will have all three contacts involved, as one cable will transport both signals for main and secondary yarn sensor. After everything is connected you may have to check if you used the right connections for main and secondary. In case they are flipped you simply have to swap the two signal cables accordingly.

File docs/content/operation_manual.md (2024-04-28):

---
title: "Operation manual"
date: "2024-03-18"
menu: "main"
weight: 4
TableOfContents: true
---

# Open Knitting Motor Project - Operation manual

## 0. TL;DR

You like videos more? See every menu function of the control box described in detail in this video:<br> [Open Knitting Motor Control box in detail](https://www.youtube.com/watch?v=B765agb7pRA)

But you should definitely come back and read about how to operate the whole system on a daily basis.

## 1. System startup

After powering on the control box, you will have to reset (aka homing) the knitting carriage once by pressing the `SELECT` button.

*Please make sure that during homing:*

- *no needles are in working position or*
- *that both PART buttons on the carriage are pressed and needles are in E position*
- *simply disengage the carriage from the mover plate. After homing, the carriage will return to the zero position on the right and the motor is ready to knit.*

To start knitting a single row right away, all you have to do is set up some rows to knit, hit the foot pedal and the motor should start transporting the carriage one complete row. After the row has finished the carriage will knit in the opposite direction if you hit the pedal again.

*You find knitting single rows to be too tedious? Me too...*<br>
No problem. If you want the motor to continuously knit a decent amount of rows, you simply setup the control box in `auto` mode (which is by default), enter a defined no. of rows and start the continuous knitting process via the buttons on the control box or with the foot pedal if it is configured for continuous knitting. See part 3. of the manual on how to do this.

***
*There is a variant regarding continuous knitting:*

If you simply want the motor to continuously knit, regardless of the row count, you can set the control box into `manual` mode. Then you can start continuous knitting and the control box will only count the rows knitted so far, but will not stop on its own.
***

If, for whatever reason, you encounter any problems (some unknown error, menu not responding, whatever) and want to start over, simply press the `RESET`button. The button will stop the motor immediately, restart the control box and you should be good to go. You will not loose the row count. I.e. the menu not responding *can* happen after one of the safety sensors was engaged.

## 2. Daily usage, the menu system and important parameters

**Needle bed position naming convention**

			                                       needle bed
			      100 ---------------------------------0---------------------------------100
			       |                  |                |                 |                |
			    max position          |                |                 |          zero position
			                          |           mid position           |
			                    left boundary                        right boundary

### General menu handling

Press and hold the `UP` button to open the menu of the control box.

- Scroll through the menu with `UP` and `DOWN` buttons
  - If submenus are available, a small arrow on the left or right of the menu item will appear. Now change the menu depth with `RIGHT` (descend) or `SELECT` (ascend) - yes, a little bit irritating that you cannot use the `LEFT`button to go left, I know...

- To edit a configuration value press `SELECT` -> a small arrow in front of the value will appear
- Change the value with `UP` or `DOWN` button
- Finish editing by pressing `SELECT` again<br>
  You can use the `Back` menu options to change the submenu one level up and the `Exit` menu command to exit the menu completely. Alternatively, you can simply wait 5 seconds, and the main menu will close. Hold in mind that the menu won't close as long as you are editing a parameter, like row count, motor speed, etc..

### Main daily usage parameters and handling

- Set row count (will be saved and reloaded)<br>
  Can be set between 1 and 999 rows.<br>The meaning of "row count" is different between operation modes:<br>
	
	- `auto` mode: Setup a number of rows to knit
  - `manua` mode: Correct the no. of rows knitted here to reflect any manual interactions which the control box can not account for on its own
  
- Boundaries (Left / Right boundary)<br>
  If you don't want to always knit the whole needle bed from left to right but rather a subsection in the middle to save time, you can set a left and right boundary for the carriage. 

  If you press `SELECT`to edit one of the boundary options the carriage will behave as follows:

  1. go to the middle of the needle bed, if no boundary has been set before
  2. return to the last saved position
  
	You can then move the carriage left and right with the corresponding `LEFT` or `RIGHT` button on the control box and the new position will be saved. A short press will move the carriage a short step, press and hold the button for a bigger step.

  Beware, that you can only set the left boundary further to the left of the middle of the bed, and it is the opposite with the right boundary. They can not be cross-set aka left boundary on the right and right boundary on the left.
  
  The boundaries don't have to be symmetrically aligned, but always have to be placed around the 0 needle position (middle of the bed).

**Carriage behaviour when you start knitting after setting up boundaries:**

If the carriage is on the zero position, it will knit to the left boundary. Is the carriage on the max position, it will knit to the right boundary. Every further row will then be knitted between these two boundaries.

#### Manual carriage movement

If, for some reason, you want to bring the carriage over to the max or zero position regardless of the boundaries set, press and hold the `LEFT` or `RIGHT` button and the carriage will first start to move to the assigned boundary. If you do exactly the same again after the carriage has reached the boundary it will move again in the same direction until the endpoint is reached. This cn be changed though in the `Settings`menu. See description of `Navigation mode`for details.

Normally, boundary values are saved. If there are any problems with the carriage endstop positions when you turn the power on and after the first calibration routine (homing), the boundary values will be automatically set to 0 and you have to dial them in again.

<u>*BEWARE: Make sure no needles are engaged while setting the boundaries!*</u>

#### The yarn sensor and its activation

In case your system is equipped with a yarn sensor, the control box is able to detect if the yarn runs out or if there is a knot in the yarn, for main and secondary color. You can activate the sensor for both colors independently, but runout and knot sensing will always be activated together per side.

So, if you activate main yarn sensor, it will automatically watch for yarn runout *and* knots in the yarn at the same time.

If the yarn sensor is activated during knitting, the following will happen:
- you get a message on screen, which you have to acknowledge by pressing `SELECT` to proceed
- the display will show an extra symbol `E` (see below for symbol description)
- the row counter will not be decreased (`auto` mode) or increased (`manual` mode) if you begin to knit again
- if you restart knitting, single row or continuous, the current row direction will be continued (!)

## 3. Configuration settings

To change any of the following parameters, open the control box menu and go to `Settings`.

- Operation mode (default: `auto`)<br>
  - `auto`: Automatic knitting according to the given row count, machine will stop when all rows are done. Continuous knitting can only be started if a row count greater 0 is set.
  - `manual`: The machine will only count the rows knitted.
  *Changing this configuration parameter will automatically clear the row count value and set it to 0.*<br><br>
- Foot pedal mode (default: `single`)<br>
  - `single`: The foot switch will start knitting one row.
  - `continuous`: The foot switch will start continuous knitting. Hit the foot switch again to stop continuous knitting after the current running row is finished.<br><br>
- Navigation mode (default: `boundary`)<br>
  - `boundary`: If you press and hold the left/right button on the control box, the carriage will move to the chosen direction up to the boundary (if set) and later, if you do this again, to the maximum or zero position.
  - `maximum`: The left/right button will always move the carriage to the maximum or zero position, regardless if you set boundaries or not.<br><br>
- Carriage speed (default: `80`)<br>
  You can raise and lower the carriage speed with a certain range. Please be careful and only raise the value in small steps and try again until it works as desired.<br><br>
- Yarn sensor main (default: `off`)<br>
  Activate or deactivate, if the control box should check for messages from the main (color) yarn sensor.
  If you don't use one, set to `off`.<br><br>
- Yarn sensor sec (default: `off`)<br>
  Activate or deactivate, if the control box should check for messages from the secondary (color) yarn sensor.
  If you don't use one, set to `off`.<br><br>
- Overload sensor (default: `off`)<br>
  Activate or deactivate, if the control box should check for messages from the overload sensor.
  If you don't use one, set it to `off`.<br><br>
- Direction arrow (default: `on`)<br>
  During knitting you will be presented with a small combination of symbols on the lower right side of the display right next to the current row count, showing you the knitting direction, if continuous knitting is active and if boundaries are set.
  If you set this option to `show`, the symbol combination will be kept on screen even after the carriage has stopped.
  If you set this to `hide`, the symbols will only be visible as long as the carriage is running.<br><br>
- Button beep (default: `on`)<br>
  If your control box is equipped with a buzzer, you can turn beeps on button press on or off.<br><br>
- Alarm tune (default: `Entertainer`)<br>
  If you are in `auto` mode and have a buzzer installed, an alarm song will be played to show that everything finished.
  Choose the one you like the most.<br><br>
- LCD backlight (default: `100%`)<br>
  If your LCD display is too bright for you, you can adjust the brightness between 33%, 66% and 100%.

## 4. Symbol description

  *Possible symbols:*

      <-  -> : running direction of the carriage
      C      : continuous knitting active
      E      : shown, if the yarn sensor was activated in current row
      [    ] : boundaries set

  Examples:
  - `[C->]`: last row was knitted to the right between boundaries and continuous knitting is on
  - `<-`   : last row was knitted to the left
  - `[E]`  : during last row between boundaries, the yarn sensor was activated<br><br>

## 5. Button usage on main screen

**Control box - button naming convention**

                                      UP
                                      |
                     SELECT -- LEFT --|-- RIGHT -- REBOOT
                                      |
                                      DOWN

| Button | Press duration | Function |
| :--- | :---: | :--- |
| `SELECT` |  short press | after power on, start homing<br>in menu, activate parameter editing or (if left arrow shown) leave submenu |
| `SELECT` | press and hold | start continuous knitting |
| `LEFT` |  short press | move carriage a short way (about two needles) to the left |
| `LEFT` | press and hold | move carriage to left boundary and/or max position |
| `UP` |  short press | in menu, edit (increase) value |
| `UP` | press and hold | open menu |
| `DOWN` |  short press | stop continuous knitting after current row<br>in menu, edit (decrease) value |
| `DOWN` | press and hold | zero values "Rows to knit" / "Knitted rows" |
| `RIGHT`  |  short press | move carriage a short way (about two needles) to the right<br>in menu, go down to submenu |
| `RIGHT`  | press and hold | move carriage to right boundary and/or zero position |

## 6. Special menu items

You find some additional, less important options in the menu:

- Boundaries / Clear boundaries<br>
  Reset boundary values to 0<br><br>
- Tools / Home carriage<br>
  Tools / Move to (start/middle/end)<br>
  Home carriage starts the self-calibration routine again you are faced with when you power on the control box.
  This can be necessary if there was a failure with the stepper motor, or after the coupler between the carriage mover and the carriage itself has been disconnected because of a blockage of the carriage.
  The `Move to...` options are only there for convenience and will behave exactly the same as the display buttons, although you can only move the carriage to the middle of the bed from here.<br><br>
- Info<br>
  Will show the current firmware version.<br><br>
- Reset all<br>
  Resets all firmware parameters to default. Please restart control box afterwards via the `REBOOT` button.

## 7. Error messages on display

| Error message | Description | Solution |
| :---- | :----- | :----- |
| HIT 1 - MAX | Endstop in maximum position was activated | press `SELECT` to clear, re-home carriage |
| HIT 2 - HOME  | Endstop in zero position was activated | press `SELECT` to clear, re-home carriage |
| YARN 3 - MAIN | Yarn sensor main color activated | check, if knot in yarn or run out |
| YARN 4 - SEC  | Yarn sensor secondary color activated | check, if knot in yarn or run out |
| ERR 1 - FOOT  | No foot switch attached | attach foot switch |
| ERR 2 - OVRL  | Overload sensor activated | clear blockage or carrier, re-home carriage |

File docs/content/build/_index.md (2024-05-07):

---
title: "Build your own"
date:  "2024-03-18"
weight: 20
---

-----

If you want to build your own personal knitting motor, you should find enough information in the following documents to achieve that.

## Techdocs

- [Parts list](/knittingmotor/build/parts_list/)

- [Firmware description](/knittingmotor/build/firmware/)

- [Electronics and Wiring](/knittingmotor/build/wiring/)

- [Assembly](/knittingmotor/build/assembly/)

- [Changelog](/knittingmotor/build/changelog/)

------

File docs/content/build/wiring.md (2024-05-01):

---
title: "Wiring"
date:  "2024-04-30"
#menu:
#  main:
#      parent: Build your own!
TableOfContents: true
weight: 40
---

## How to wire all parts?

I try to describe how I wired everything together the best I can. Sorry, no schematic available atm, but it should not be too complicated. If I find the time I will try to add schematics.

## PIN defaults

See `include\HardwareConfig.h` for the pin assignment defaults.

The minimum sensor (aka switch) pins you have to use are:
- home endstop
- max endstop
- foot switch

*Regarding yarn sensor / overload sensor pins:
You HAVE to assign valid pin numbers, even though you do not have to use the sensors as of the current firmware implementation.*

### Changing the PIN assignment
If you want to change the pin assignment to the Arduino for any reason, you will have to change the associated values in `include\HardwareConfig.h` and recompile the firmware.

## External connectors

    GX16 4pin                   : stepper motor connection
    GX16 4pin                   : rotary encoder
    Stereo plug (GND + Tip)     : endstop max (left side of needle bed)
    Stereo plug (GND + Tip)     : endstop zero (right side of needle bed)
    Stereo plug (GND + Tip)     : foot switch
    Stereo plug (GND + Tip)     : overload sensor
    Stereo plug (GND, Ring, Tip): yarn sensor (main+secondary)

## Common connection rails

### GND connection rail

    Arduino / LCD Shield
    all switches
    rotary encoder
    passive buzzer
    main frame and stepper motor

You *can* omit the ground connection to the frame and stepper motor, but I would not recommend ist. The running belt will 	create some kind of electrostatic charge which will interfere with the endstops. I had the problem that the max endstop triggered just by touching it. After adding a ground wire which connected the frame to one of the mount screws of the stepper motor and then to the main ground rail, this problem was gone. So, keep that in mind!

### VIN (+5V) connection rail

    rotary encoder
    TB6600/DM542T Ena+
    TB6600/DM542T Dir+
    TB6600/DM542T Pul+
    passive buzzer

## Power supply

    24V volt to TB6600/DM542T
    24V volt to LM2596 Buck (In)

**Set Buck converter to 9-12 Volt - depends a bit on the fan you use.**

## Buck converter

    GND (Out): Arduino/LCD Shield GND
    GND (Out): Fan
    V+ (Out): Arduino/LCD Shield VIN
    V+ (Out): Fan

## Arduino + LCD Keypad Shield

Simply plug them together ;-)

Because of the design of the upper housing, you will have to solder wire connections and plugs to all available connectors on the LCD Keypad Shield, which are: D0-D3, D11-D13, A1-A5.

## LCD Keypad Shield

    D0:  passive buzzer
    D1:  overload sensor
    D2:  Rotary Encoder A
    D3:  Rotary Encoder B
    D11: TB6600/DM542T Pul-
    D12: TB6600/DM542T Dir-
    D13: TB6600/DM542T Ena-
    
    A1:  yarn sensor secondary
    A2:  yarn sensor main
    A3:  footswitch
    A4:  endstop max
    A5:  endstop zero

## TB6600 / DM542T

Use a GX16 connector.

(Only outgoing connections described, see VIN rail and LCD Keypad Shield for the rest of the connections.)

A+ / A- / B+ / B-: to stepper motor via GX16 connector

*Hint:
To find out, which cables belong to which phase, simply hold two wires together and try to turn the motor by hand. If you feel quite a lot of resistance while the cables are held together, you found a phase ;-)*

After you hooked up the motor, you will have to check, if your wiring leads to the correct turning direction of the stepper. As a hint, if you mount the GT2 pulley to the motor and look right at it, the motor has to turn CCW when moving the carrier to the zero (right) position and CW to the max (left).

If the motor turns the opposite way, then simply rewire the cables on motor connector on the driver the other way around.

See this as example for rewiring the direction:

    A+: white    -> becomes   A+: green
    A-: blue     -> becomes   A-: brown
    B+: brown    -> becomes   B+: blue
    B-: green    -> becomes   B-: white

Regarding DM542T: make sure that the control voltage switch on top is set to 5V, or nothing will happen - don't ask how I know...

## Rotary enoder

Use a GX16 connector.

    GND  : Arduino GND **(!IMPORTANT!)**
    5V   : Arduino 5V - you have to make sure, that your Arduino
           DOES deliver real 5V, not 4.98V or something **(!IMPORTANT!)**
    GREEN: D2
    WHITE: D3

## Endstops and sensor pins

Use the stereo connectors.

See description under **LCD Keypad Shield** to find out where every switch has to be connected to. They are all tied to GND.

Only the yarn sensor will have all three contacts involved, as one cable will transport both signals for main and secondary yarn sensor. After everything is connected you may have to check if you used the right connections for main and secondary. In case they are flipped you simply have to swap the two signal cables accordingly.

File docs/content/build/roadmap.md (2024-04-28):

---
title: "Roadmap"
date:  "2024-04-19"
#menu:
#  main:
#      parent: Build your own!
weight: 60
TableOfContents: true
---

## Things could get better over time...

Although I am quite happy with how the system is working today, things can always be improved.

### Control box

- Optimize display performance of control box in case of an error<br>
	In case one of the sensors (yarn, overload, endstop) got hit it can happen, that the display will begin to flicker or at least need some time until the error message is clearly blinking on the screen. It does not happen all the time and I am not quite sure atm why it does that. Might have to do with how the main firmware loop is working. Has to be investigated further.<br><br>
- Poweroff stepper motor while the carriage is not running<br>
  At the moment, when the carriage is not running, the stepper motor is still powered by the driver, so that the control box does not loose track of its position in relation to the knitting bed. This has the sideeffect that you cannot move the carriage by hand while it is being coupled to the carriage mover. As the system already has a rotary encoder attached to it, it should be possible to poweroff the stepper motor and correct its internal position from any manually introduced positional deviance based on encoder position calculations. This would make moving the carriage by hand possible without disconnecting the coupling bolt and also save some power.<br><br>
  Technical background:<br>The stepper needs 1600 steps/rev and the rotary encoder delivers 2400 pulses/rev, so we can say that moving the stepper to any direction manually changes the current positional step value by *[0.6&#773; x no. pulses = **Δ** steps]*.<br>I already made some tests regarding the positional error between the stepper motor steps, which is controled by the driver, and the pulses the rotary encoder returns while the motor is turning: I get about 20 pulses difference while the motor is running, and about 5 pulses when it is not moving. As the rotary encoder returns 2400 pulses/rev I think its preciseness should be enough and we can ignore the pulse errors here. Otherwise we would have to introdice some kind of error map based correction which can get reeeaallyyy tricky!<br>

### 3D printed parts

- ~~The sensor mount for the overload sensor is currently mounted towards the front end of the spring lever near the spring. This is not the best for real fine adjustment of the sensor as the lever's movements naturally are much bigger at its front end than on its back end. I plan to reposition it to the back of the lever near the bolt so that smaller adjustments of the sensor mounting plate are necessary to cover a wider (and so logically more precise) adjustment range.~~ <br>Done. See `mover_plate_v2.stl` and additional chapter in the assembly documentation.<br><br>
- Due to feedback of the community (Thanks, Klaus!) I might think of offering the possibility to replace the endstop switches with reed switches or even hall effect sensors for contact-less switching. Reed switches could even be placed inside the groove of the aluminium extrusion which would literally make them disappear from the outside frame structure, what I'd prefer here. Have to think about it...

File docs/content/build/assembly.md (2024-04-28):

---
title: "Component assembly"
date:  "2024-03-18"
#menu:
#  main:
#      parent: Build your own!
weight: 20
TableOfContents: true
---

## What you'll find here and what not...

This assembly guide is not the "a) connect this to that b) now screw together blabla" type of guide, but more an overview of how things go together in general. I.e. I will not give an exact type, length or amount of screws, nuts and bolts for most of the parts, especially because sizes are not *that* critical in most cases or because, for some people, metric hardware won't be easily available in some countries.

But as a rule of thumb

- use washers wherever appropriate (don't force the screw heads into the plastic)
- screws for the basic frame are M5
- the carriage mover needs M3-M6
- the belt tensioner depends on M4
- most of the other and smaller parts, like endstop mounts, yarn sensor, control box, etc. need M3. 

Many of you will already have a decent assortment of screws, nuts and washers in different sizes at home, so it is up to you. If you really run into problems and don't know what to do, feel free to contact me via [Printables](https://www.printables.com).

Depart from that, in case it is necessary to maintain functionality I will be more precise.

If your T-nuts can only be slid in from the sides of the extrusion, make sure that you have enough T-nuts in place before beginning to screw things down. Don't ask me how I know, that you would have to disassemble more or less parts again, if a T-nut is missing...

I will describe the main components a bit more in depth now, but you will have to take a decent look at the photos and CAD drawings to get the whole picture of how it is done. As I said, the built is not for the faint-hearted :D

------

## 1) Frame

|Frame only|
| :--:|
|{{< figure src="/knittingmotor/images/CAD_frame.png" link="/knittingmotor/images/CAD_frame.png" target="blank" title="(click to zoom)" height="60%" width="60%" >}}|

I left out the knitting machine in this picture for better visual clarity. In reality, because of the table clamps, you start by fixing the knitting machine to the table, because you simply place the frame around it.

Assembling the frame first and bolting everything to the table later is totally possible though. I screwed the whole frame together, fixed  the machine to the table and positioned the frame. Here is how...

*Wording, or how I call the extrusions to name them independently:*

- *top horizontal long extrusion: run bar*
- *bottom horizontal long extrusion: front rest bar*
- *right/left horizontal short extrusions: feet*
- *right/left upright short extrusions: posts*

<u>The frame itself</u>

- The frame is straightforward. Use the corner brackets to connect the front rest, feet and mount post extrusions and make sure everything is square. I only used the corner brackets, but for added stability you could drill holes in the front rest bar, cut threads into the feet and screw them together. But it really isn't necessary.
  Regarding position of the posts, you can start about 105mm from the front rest bar as a starting point. You will have to fine adjust their horizontal (back to front) position later, when the carriage mover is attached.
- Add the `frame T-joining plate.stl`s at the sides for stability and stiffness.
- Loosely screw the `frame barclamp.stl`s in combination with the `frame vertical stiffner left.stl` and  `frame vertical stiffner right.stl` (naming is according to looking at them from behind the machine) to the run bar, then slide the clamps over the posts on both sides, leaving about 5mm of each post free above the clamps. Lock the barclamps and stiffners down, make sure, the run bar is positioned equally distant over the knitting machine. The height is a starting point. You may have to adjust the height of the run bar later when attaching the carriage mover though.

|Post back|
| :--: |
|{{< figure src="/knittingmotor/images/CAD_post_back.png" link="/knittingmotor/images/CAD_post_back.png" target="blank" title="(click to zoom)" height="40%" width="40%">}}|

- Slide the two `frame belt slider.stl` over the top of the posts and see if everything fits together nicely. The two sliders are for general protection and to hide the cables for the endstops later.

|Post back with slider|
| :--: |
|{{< figure src="/knittingmotor/images/CAD_post_back_with_belt_slider.png" link="/knittingmotor/images/CAD_post_back_with_belt_slider.png" target="blank" title="(click to zoom)" height="40%" width="40%" >}}|

- Add the last two corner brackets to the top groove of the rest bar and slide them both to the middle of the bar. Their upright edges have to point away from each other.

<u>Mounting everything to the table</u>

- Use the ribber clamps to fix the knitting machine to the table.

- Now position the frame over the machine, so that the rest bar sits on the inward curve of the machine clamp (see picture) and that the machine is evenly spaced between the feet of the frame.
  And before you ask, yes, that will tilt the whole assembly a slight amount to the back and that's totally fine :-)

- Slide the two corner brackets in the top groove of the rest bar outwards until they hit the ribber clamps, screw them down.

- Slide  `frame main clamp left.stl` and `frame main clamp right.stl`into place and screw them down with an M5 bolt, for convenience supported via a `M5_screw_knob.stl`. These nice knobs will will make removing the whole frame when disassembling much easier.

|Front rest with clamp|
| :--: |
|{{< figure src="/knittingmotor/images/CAD_front_rest_with_with_clamp.png" link="/knittingmotor/images/CAD_front_rest_with_with_clamp.png" target="blank" title="(click to zoom)" height="40%" width="40%" >}}|

### Positioning of the left and right endstop switches

At first mount the endstop switches to the `endstop_mount.stl` and then loosely fit them to the left and right end of the run bar. Later, after you have attached the carriage mover, you will have to adjust their position so that the carriage can be moved over the whole bed from left to right or even a bit further, i.e. to use a color changer.

## 2) Carriage adapter

No CAD images here. Remove the original handle from the carriage by removing the two grub screws. Then slide the carriage adapter plate in position and screw it down. Last, attach the new handle bar.

{{< figure src="/knittingmotor/rl/pictures/carrier_handlebar.jpg" link="/knittingmotor/rl/pictures/carrier_handlebar.jpg" target="blank" title="(click to zoom)" height="60%" width="60%" >}}

## 3) Carriage mover

|Mover front | Mover back |
| :--: | :--: |
|{{< figure src="/knittingmotor/images/CAD_mover_front.png" link="/knittingmotor/images/CAD_mover_front.png" target="blank" title="(click to zoom)" height="60%" width="60%" >}}|{{< figure src="/knittingmotor/images/CAD_mover_back.png" link="/knittingmotor/images/CAD_mover_back.png" target="blank" title="(click to zoom)" height="60%" width="60%" >}}|

See the following pictures on how to assemble the carriage mover.

- The screws I left intentionally in the picture have to be M6.
- The gantry is fixed by using M4 screws.
- For the `mover belt holders left/right.stl` use M3 screws and support them with washers.
- The `mover overload sensor mount.stl` does need an addtional M3 screw, this one can be screwed in to the plastic carefully.

If you bought a 4-wheel 2020 gantry, simply reassemble it to a 3-wheel version.

***BEWARE: I MISSED the `endstop bracket.stl`  in the exploded views, but I think you get the point from the front and back images above.***

|Mover assembly front|
| :--: |
|{{< figure src="/knittingmotor/images/CAD_mover_assembly_front.png" link="/knittingmotor/images/CAD_mover_assembly_front.png" target="blank" title="(click to zoom)" height="60%" width="60%" >}}|

- You don't have to attach the `mover overload sensor mount.stl` and the little switch right now. You can add it later while assembling the electronics. The switch cable though has to be guided on the left side around the `mover plate.stl`to the front, can then be guided through the small channel on the backside of `mover endstop bracket.stl` and fed to the top of the plate.

|Mover assembly back|
| :--: |
|{{< figure src="/knittingmotor/images/CAD_mover_assembly_back.png" link="/knittingmotor/images/CAD_mover_assembly_back.png" target="blank" title="(click to zoom)" height="60%" width="60%" >}}|

- The small `mover spring presser.stl`, which helps compressing the spring with the tensioner screw, is shown only once on the pictures. If you find that your compression spring is not strong enough, before grabbing a new one, add a second `mover spring presser.stl` on the top of the spring. This might help already.

If everything went together well, try to slide the mover over the run bar to see if it runs smoothely and without any wobble or wiggle. If it is too tight or too loose, you have to adjust the position of the rolers. If you don't know how, [OpenBuilds setup video on YT, beginning 2:38](https://youtu.be/pMtHy7sDNG4?t=159) is your friend, but as a hint, two of the rolers are mounted excentrically and you can adjust their position.

### Frame adjustment

Now, with the carriage mover attached to the run bar you can fine tune the whole frame.

- slide the carriage to the middle of the bed
- slide the carriage mover to the middle of the bed, straight above the carriage
- add the `carriage bolt.st` to the carriage adapter and see if it couples the carriage to the mover
- adjust the position of the posts back to front and the height of the run bar, so that the coupling mechanism connects easily and without much play
- slide both to the far left and far right to see if there are any positional inconsistencies you might have to fix

Take this as reference:
{{< figure src="/knittingmotor/rl/pictures/carrier_coupling_side_view.jpg" link="/knittingmotor/rl/pictures/carrier_coupling_side_view.jpg" target="blank" title="(click to zoom)" height="30%" width="30%" >}}

### Overload spring adjustment

The tension of the spring has to be adjusted in combination with the belt tension. The most accurate way is by knitting a test piece with the tightest stich possible. Start with the lowest spring tension possible. The spring lever should not wiggle around freely up and down, but should be pressed firmly against the spring. If you find that the mover disconnects from the carriage too easily while knitting your test piece, increase the tension of the spring. It should be tight enough so that you are able to knit everything you want, but not so tight that the mover won't disconnect in case of a blockage of the carriage, which on the other hand can lead to the timing belt slipping or even damaging your carriage. So be careful when dialing in the correct tension. 

### Overload sensor position adjustment

You will have noticed, that you can adjust the position of the overload sensor closer to the spring lever or more far away from it. This helps to get the moment where it triggers just right. Its main function is to stop the mover when there is a blockage of the carriage and the coupler has disconnected. As this depends on spring tension and how you setup the strength of the spring lever action, I can only give a general advice here. You have to setup the sensor trigger point in a way that it will be activated in the moment the spring lever is raised up and has disconnected the mechanical coupling to the carriage.

### Regarding `mover_plate_v2.stl`

|Mover plate v2|
| :--: |
|{{< figure src="/knittingmotor/images/CAD_mover_plate_v2.png" link="/knittingmotor/images/CAD_mover_plate_v2.png" target="blank" title="(click to zoom)" height="40%" width="40%" >}}|

I noticed that fine adjusting the overload spring and overload sensor position can be a bit tricky, if the switch is in the front position (near to the spring), because the spring lever is moving in a wider range up and down at its front than at its back. So I added a second (optional) sensor position more to the back of the lever, where a more finer adjustment of the sensor position will be possible. Choose whatever position is suitable for the spring and switch  combination you bought. 

*Keep in mind, in case of a blockage the goal is to first) have the carriage mechanically disconnect from the mover before second) the switch opens - at least shortly one after the other.*

## 4) Yarn sensor

|Yarn sensor assembly|
| :--: |
|{{< figure src="/knittingmotor/images/CAD_yarn_sensor.png" link="/knittingmotor/images/CAD_yarn_sensor.png" target="blank" title="(click to zoom)" height="60%" width="60%" >}}|

The yarn sensor is the most complex and intricate build of the whole system. As it would be a bit hard to describe how everything goes together,  I suggest taking a closer look at the photos to see how it is done.

### How does it work?

The yarn sensor is capable of sensing a) yarn runout and b) knots in the yarn for the main (right) and the secondary (left)  thread. To achieve this, there are four reed (aka magnetic) contacts on the underside of the sensor which act in combination with the four levers, which are equipped with a small magnet each. Every lever / reed contact combination will therefor form a single switch and the two sensors (front and back) on each of the sides will form a unit, which means both sides are measured independently, but always the front and the back sensor element together.
So, if either the right runout sensor lever (front) or the right knot sensor lever (back) is engaged, the control box will report an error regarding the right (main) yarn sensor - same for the left (secondary) side.

**Yarn runout**
The switch in the front will be closed when yarn is fed through the sensor, as the thread will hold the corresponding lever up, which will close the reed contact. If the yarn runs out, the lever will drop, which will open the contact and can then be sensed by the control box.<br>
*-> The contacts in the front are "**normally open**" reed contacts.*

**Knot sensing**
If a not comes up from the cone it will be trapped in the small slit in the back lever, raise the lever and, in this case, open the reed contact. This will also lead to a message on the display of the control box.<br>
*-> The contacts in the back are "**normally closed**" reed contacts.*

|Yarn sensor top |Yarn sensor bottom |
| :--: | :--: |
|{{< figure src="/knittingmotor/images/CAD_yarn_sensor_assembly.png" link="/knittingmotor/images/CAD_yarn_sensor_assembly.png" target="blank" title="(click to zoom)" height="60%" width="60%" >}}|{{< figure src="/knittingmotor/images/CAD_yarn_sensor_assembly_underside.png" link="/knittingmotor/images/CAD_yarn_sensor_assembly_underside.png" target="blank" title="(click to zoom)" height="60%" width="60%" >}}|

I recommend taking a look at the [pictures](/knittingmotor/rl/) I took during the build so that you can see how the reed contacts have been placed and how the wiring is done.

### Assembly

- The main plate consists of two parts, `yarn sensor base.stl` and `yarn sensor base screw mount.stl` to make it easier to print. You have to insert the `yarn sensor base screw mount.stl`from the top of the base plate (mind its orientation, the fin has to point to the rear of the plate!) and glue it in place. Make sure it is sitting flush and straight in its position.
- Glue the reed contacts into place (small recesses). That means, the two "normally open" contacts in the front and the two "normally closed" ones two the back. Double check that you are about to glue the right ones into place! I recommend to temporary fix them to the plate and check with a multimeter and a magnet if their orientation is just fine and if they react to the distance of the magnetic as necessary. Especially the "**normally closed**" ones in the back should be checked. They have a small hump on one of the four sides and this hump should be facing downwards. The "**normally open**" reed switches don't have this hump and are not as sensitive to misorientation than the others.
- Then, on either side, connect the front contact two the back contact. If you take a look at the [photo](/knittingmotor/rl/pictures/yarn_sensor_build_1.jpg) I took during the build you can see, that I put a little piece of adhesive aluminium tape under the connection and soldered both contacts as flat as possible together. If you want to do it the same way, keep in mind, that you solder above plastic. Try to position the solder point the same way as I did, because you need some room inward between the solder point and the screw mount. The back lever (knot sensor part) which we attach later has to be able to move freely up and down and should not be blocked by the solder point.
- Next, begin to attach the cables to the contacts. See [this photo](/knittingmotor/rl/pictures/yarn_sensor_build_2.jpg) how I did that. Guide the front cables to the back, then attach the back cables. You should secure the cables by glueing them right to the base plate, so that they will not interfere with the levers. You can use CA glue as me, or a thin (!) layer of hot glue. There is not much room for everything, but I think you get the point. I used a little bit of shrink tubing to make sure nothing comes in contact with each other. You can now connect the two cables coming from the front of either side together, but leave the two cables from the back separated, so that you now have 3 connections which will later be attached to the stereo jack: the two single cables to tip (main) and ring (secondary), and the two connected ones to the sleeve contact.
- After that, it is just a matter of a bit of smart cable management - I used a little bit of a somewhat stiffer shrink tubing to [*model* the way the cables go](/knittingmotor/rl/pictures/yarn_sensor_build_3.jpg) between the back lever arms. As soon as the shrink tubing cooles down, the cables will be fixed and won't interfere with anything anymore. You can also see there what I meant by 3 cable contacts that I mentioned earlier.
- Now, assemble the levers. I used nylon washers between everything to have as little friction as possible. You can also use thin metal washers, but you cannot omit them completely, as the tolerances between all parts account for them.
- Add the magnets to the little tubes, but don't glue them into place right now, we have to fine tune their position first.

#### Adjust the mechanical play
Use a nylon lock nut along with the central screw to adjust the play of the lever movement. The four levers should move up and down freely, but make sure that they don't wiggle around sideways, as this will lead to unreliable behaviour, especally with the back (knot) sensor elements. Using a lock nut is a good way to adjust the play in very small steps, as the difference  between too loose and too tight is rather small.

#### Fine tuning of the magnet positions

The magnets have to be placed inside the small tubes of the front and back levers in a way that moving the levers up and down will activate or deactivate the corresponding reed contact directly above them. I can only give a general advice for calibrating the magnet position,  because I don't know the actual strength of the magnets you bought, but you have to position the magnets in such a way, that

- the front levers can actually move a little bit up and down without deactivating the reed contact, but open the contact when you let them swing down completely
- the back levers (which have much less room to move up and down!) should open the reed contact *only* when the lever is really close or touching the reed contact

If the force of the magnets is too strong, it can help to move them sideways in relation to the reed contact inside the tube to reduce the magnetic field impact. Use a multimeter connected to the back and front reed contact to see if it works.<br>The multimeter should detect a closed connection when 

- a) the front lever is in up and 
- b) the corresponding back lever in its down position.

If you are happy with how everything works, simply glue the magnets in place so that they cannot leave their calibrated position anymore. To even more secure the magnets you can insert one of the small `yarn sensor magnet plug.stl` on either side of the tube and glue them into place, too.

## 5) Stepper and rotary encoder assembly

|Stepper assembly|Rotary encoder assembly|
| :--: | :--: |
| {{< figure src="/knittingmotor/images/CAD_stepper_assembly.png" link="/knittingmotor/images/CAD_stepper_assembly.png" target="blank" title="(click to zoom)" height="60%" width="60%" >}} | {{< figure src="/knittingmotor/images/CAD_rotary_encoder_assembly_detail.png" link="/knittingmotor/images/CAD_rotary_encoder_assembly_detail.png" target="blank" title="(click to zoom)" height="60%" width="60%" >}} |

Assembling the attachement for the rotary encoder and completing the whole stepper motor setup is really straight forward. Although the `rotary encoder shaft coupler.stl` between the rear motor shaft and the rotary encoder will allow for some misalignment, try to make sure that there is no play in the back assembly and that everything is tight and straight.

As a last step, slide the `frame stepper mount.stl`over the right end of the run bar. The stepper assembly has to point to the back. At first, just barely screw it down. After having attached the timing belt you can then first pull the stepper assembly outward and screw it down to pre-tension the belt before further tensioning of the belt with the belt tensioner on the left.

### Regarding the rotary encoder bracket

The bracket consists of three parts for easier and support-less printing:
- `rotary encoder bracket base left.stl`
- `rotary encoder bracket base right.stl`
- `rotary encoder bracket bridge.stl`

It can be a bit fiddly to get all three parts together and you will have to bend the legs of the bridge a bit until everything snaps together. As a hint, you should first insert the legs of the bridge into the base parts from the top and then lightly force everything into place. I assure you it will work, work slowly and carefully.

## 6) Belt tensioner

|Belt tensioner|
| :--: |
|{{< figure src="/knittingmotor/images/CAD_belt_tensioner.png" link="/knittingmotor/images/CAD_belt_tensioner.png" target="blank" title="(click to zoom)" height="40%" width="40%" >}}|

Use M4 screws, washers and nuts to assemble everything. Take a close look at the picture to find out the correct direction of the arms left and right. The tensioner screw has to go on the underside of the run bar. If you screw the tensioner screw inwards, it pushes against the `belt_tensioner_pusher.stl` and will then move the idler pulley outward. This will tension the belt.

I know that the bore hole of the GT2 idler pulley is 5mm, but we are using M4 screws here. This hasn't led to any problems in my setup. If you are worried about that, simply widen the slot where the screw is sliding up and down in the arms and use a M5 screw instead.

### Attaching and tensioning the belt

- Unscrew the tensioner screw the whole way out

- Attach the belt to one side of the carriage mover by sliding a small loop into the belt holder - the belt will be secured by friction and grabbing itself, use the `GT2_clip.stl`to secure it

- Now guide the belt around the frame - it has to run through the upper and lower groove of the aluminium extrusion - *thread* it through the tensioner and the stepper mount

- Take out the slack as good as possible and attach the loose end to the other side of the carriage mover, use the `GT2_clip.stl`to secure it

- Now tighten the tensioner screw again to further tighten the belt, but please don't overtighten it!

**As a guideline:**<br>
The belt tension and the tension of the overload spring on the carriage mover depend on each other. The whole adjustment should be set up in a way that, under normal conditions, the belt doesn't slip while knitting and it shouldn't slip also when the carriage is blocked, so that the coupler mechanism can disconnect the carriage from the mover. But if your overload spring is too tight, then the belt might slip anyhow and the carriage will never be disconnected.

- If the belt feels quite tight, knit a test piece with the tightest stich setting.  If the carriage mover starts to slip while knitting normally, re-tighten the belt.<br><br>

  - Try to block the carriage during its movement with your hands - do that without having any needles engaged, just for safety. If the belt slips before the carriage coupler disconnects the carriage, re-tighten the belt.

## 7) Control box

|Assembly views| |
| :--: | :--: |
| {{< figure src="/knittingmotor/images/CAD_control_box_assembly.png" link="/knittingmotor/images/CAD_control_box_assembly.png" target="blank" title="(click to zoom)" height="60%" width="60%" >}} | {{< figure src="/knittingmotor/images/CAD_control_box_upper_parts_connection.png" link="/knittingmotor/images/CAD_control_box_upper_parts_connection.png" target="blank" title="(click to zoom)" height="60%" width="60%" >}} |
| {{< figure src="/knittingmotor/images/CAD_control_box_upper_part_inside_view.png" link="/knittingmotor/images/CAD_control_box_upper_part_inside_view.png" target="blank" title="(click to zoom)" height="60%" width="60%" >}} | {{< figure src="/knittingmotor/images/CAD_control_box_upper_part_1.png" link="/knittingmotor/images/CAD_control_box_upper_part_1.png" target="blank" title="(click to zoom)" height="60%" width="60%x" >}} |

- To attach the display mount to the main upper housing, simply slide the two small tabs in the front of the display mount in position and put in the screws to hold the mains connector in place, this will fix everything nice and tidy. It is a bit hard to describe, but take a look at the second image and you should see how this is going together.
- The stepper driver is held in place by friction. If your tolerances are a bit too loose you can use a bit of double sided tape to hold it in place.
- The fan has to blow the air *out* of the housing to achieve a good airflow.
- The power supply is just laying down inside the box. As I do not expect anyone to turn the control box upside down or shake it like crazy, there is simply no need for screws to hold it in place.
- I added two additional holes for GX16 connectors to the upper housing on purpose, which are not in use atm. Close them with two `control_box_GX16_blind_plug.stl`. On the other hand, you could substitute the stereo jack connectors with GX16 connectors if you want,  but you will have to adapt the wiring in this case.

*As a sidenote, I know that there is not much room between the mains connector and the underside of the stereo jacks but this is no problem as long as you take care of isolating every single connector seriously. I used relatively thick shrink tubing around everything and it works without any problems.*

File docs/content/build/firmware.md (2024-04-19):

---
title: "Firmware"
date:  "2024-04-04"
#menu:
#  main:
#      parent: Build your own!
weight: 30
TableOfContents: true
---

The project is being developed under Visual Studio Code with the PlatformIO plugin. If you use the same IDE, you should not have any problems compiling and flashing the firmware to the Arduino, as all necessary external libraries will be configured via `platformio.ini`.

## 1. Pre-built firmware download

The firmware is (theoretically) available in two different versions:

- Arduino R4 support (`r4wifiv2` branch)
- (Arduino R3 support (`master` branch) - OLD - NOT SUPPORTED ANYMORE - ONLY FOR REFERENCE - DONT USE!)

[-> Always get latest firmware release here!](https://gitlab.open-mind.space/pages/knittingmotor/-/releases/permalink/latest)

## 2. Firmware pre-build configuration

Under normal circumstances you should use my pre-defined pin assignments, but in case you want to change something, you will have to adopt your changes before compiling the firmware. 
Open include/HardwareConfig.h and make all necessary changes.

<u>*Please only change any of the hardware parameters, like stepper and encoder resolution, if you exactly know what you are doing.*</u>

## 3. Language configuration

The firmware initially comes in two different languages at the moment, German or English. You can change this in `platformio.ini` via the `build_flags` parameter:

- -D LANG_DE (for German) 
or
- -D LANG_EN (for English)

I did not build a live language option into the firmware, as it won't happen too often that a user wants to change the language while using the machine. So, the language will be compiled directly into the firmware.

If you want to add another language, see `Lang.h` for how it is done.

## 4. Serial debug options

If you want to enable some more (serial) DEBUG options, you can setup some additional `build_flags` in platformio.ini:

- -D DEBUG: will enable general debug output, has to be defined always for debuggin
- -D DEBUG_APPMODE: will generate debug messages regarding the firmware operation itself
- -D DEBUG_POSITION: will generate additional information regarding the stepper and encoder operation

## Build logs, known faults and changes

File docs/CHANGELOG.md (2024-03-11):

# ChangeLog

| FW Version | Gitlab branch | Comment |
| --- | --- | --- |
| v0.4.2-prod | master | first public release |
| v0.4.6+65 | master | features ready (Arduino UNO R3 only!) |
| v0.4.6+78 | r4wifiv2 | featurewise same as v0.4.6+65, but for Arduino UNO R4 (only!) support|

As I find it too tedious to list every change in the changelog here, I will only sum up milestones more or less. You can find more detailed version information via `git log`.

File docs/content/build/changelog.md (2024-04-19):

---
title: "ChangeLog"
date:  "2024-04-04"
#menu:
#  main:
#      parent: Build your own!
weight: 50
---

| FW Version | Gitlab branch | Comment |
| --- | --- | --- |
| v0.4.6+138 | r4wifiv2 | main branch, don't use `master` branch anymore, dropped Arduino UNO R3 support|
| v0.4.6+78 | r4wifiv2 | featurewise same as v0.4.6+65, but for Arduino UNO R4 (only!) support|
| v0.4.6+65 | master | features ready (Arduino UNO R3 only!) |
| v0.4.2-prod | master | first public release |

As I find it too tedious to list every change in the changelog here, I will only sum up milestones more or less. You can find more detailed version information via `git log`.

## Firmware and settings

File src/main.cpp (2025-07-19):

/*!`
 * \file main.cpp
 *
 * This file is part of Open Knitting Motor Project OKMP.
 *
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
 *    Original Work Copyright 2024 Holger Pandel
 *    http://pages.open-mind.space/knittingmotor
 */

#include <string.h>
// #include <TimerOne.h>
#include <strlcpy.h>
#include <LiquidCrystal.h>
#include <MobaTools.h>
#include <anyrtttl.h>
#include <pitches.h>
#include <Bounce2.h>
#include "LcdKeypad.h"
#include "MenuData.h"
#include "Config.h"
#include "HardwareConfig.h"
#include "RTTTLTunes.h"
#include "Version.h"
#include "Lang.h"

// make real string from preprocessor text
// #define _STRINGIZE(x) #x
// #define STRINGIZE(x) _STRINGIZE(x)

// bit manipulation macros
#define clear_bit(a, z) (a &= ~_BV(z))
#define set_bit(a, z) (a |= _BV(z))

#if !defined(VERSION)
#define VERSION 0.0.1 - dbg
#endif // VERSION

// possible debug macros
// #define DEBUG_APPMODE
// #define DEBUG_POSITION
// #define DEBUG_DISPLAY

#ifdef DEBUG_APPMODE
#define DEBUG
#endif
#ifdef DEBUG_POSITION
#define DEBUG
#endif
#ifdef DEBUG_DISPLAY
#define DEBUG
#endif

// define macros for debug output
#ifdef DEBUG
#define DBG_PRINT(...) Serial.print(__VA_ARGS__)     // DBGPRINT is a macro, debug print
#define DBG_PRINTLN(...) Serial.println(__VA_ARGS__) // DBGPRINTLN is a macro, debug print with new line
char dbgbuf[100];
#else
#define DBG_PRINT(...)   // now defines a blank line
#define DBG_PRINTLN(...) // now defines a blank line
#endif

#define STEP_CW 1
#define STEP_CCW -1
#define STEP_STOP 0

// error and warnings
enum ErrorStates : byte
{
  OK,
  HIT_HOME,
  HIT_MAX,
  HIT_YARN1,
  HIT_YARN2,
  ERR_OVRL,
  MISS_FOOT
};

// app states
// APP_PGMSTART - program just started, not homed and uninitialized values on LCD screen
// APP_DISP_UPD - repeated homing done, but display needs update
// APP_PRE_CHECK - basic checks, if all necessary sensors are attached
enum AppModeValues : byte
{
  APP_PRE_CHECK,        // 0
  APP_PGMSTART,         // 1
  APP_DISP_UPD,         // 2
  APP_NORMAL_MODE,      // 3
  APP_CARRIAGE_RUNNING, // 4
  APP_ALARM,            // 5
  APP_MENU_MODE,        // 6
  APP_PROCESS_MENU_CMD  // 7
};

// different main screens to show during APP_NORMAL_MODE
enum Screens : byte
{
  STEPS,
  ROWS,
  ROWS_WITH_HEADER
};

// Rotary encoder params
unsigned int oldEncPosition = 0;
volatile unsigned int newEncPosition = 0;
int encDir = STEP_STOP;

// Stepper pins params
long stepperMaxPos = 0; // max endstop
long stepperMidPos = 0; // mid position after homing
byte stepperAttached = 0;
int operationRPM = 0;

long posFromEnc = 0; // calculated stepper position from encoder

// error relevant variables
byte errorState = OK;              // endstops/sensors hit? (0=ok,1=max endstop,2=home endstop,3=yarnsensor)
short errPreservedDir = STEP_STOP; // preserve old direction in case of an error

// temporary button request, later changed with menu
const char EmptyStr[] = "";
char strbuf[LCD_COLS + 1]; // one line of lcd display

// knitting related
unsigned int currentRowCount = 0;
unsigned int oldRowCount = 0;
byte knitRow = 0;        // switch to knit 1 row
byte knitContinuous = 0; // switch to control continuous knitting
byte fpHit = 0;          // footpedal hit switch

// error and display related
unsigned long menuStartTime;
byte arrowShown = 0;         // arrow on display?
byte startupDisplayed = 0;   // is showing startup display
byte errorDisplayed = 0;     // controls blinking of error message
byte displayErrorSymbol = 0; // show continue screen after error

MoToStepper myStepper(stepsPerRev, STEPDIR);
LiquidCrystal lcd(rsPin, enablePin, d0Pin, d1Pin, d2Pin, d3Pin);
AppModeValues currentAppMode = APP_PRE_CHECK;
AppModeValues nextAppMode = APP_PRE_CHECK;
MenuManager Menu1(knittingMenu_Root, menuCount(knittingMenu_Root));
Config currentConfig;
Screens screenToShow = ROWS_WITH_HEADER;
Bounce2::Button footswitchBtn = Bounce2::Button();
Bounce2::Button homeBtn = Bounce2::Button();
Bounce2::Button maxBtn = Bounce2::Button();
Bounce2::Button yarnMainSens = Bounce2::Button();
Bounce2::Button yarnSecSens = Bounce2::Button();
Bounce2::Button overloadSens = Bounce2::Button();

byte btn; // menu button

// timed actions always like this (!)
const unsigned long REFRESH_INTERVAL = 600; // display refresh when blinking in ms
/*
  static unsigned long lastRefreshTime = 0;
    ....
    if(millis() - lastRefreshTime >= REFRESH_INTERVAL){
      lastRefreshTime += REFRESH_INTERVAL;
      // DO SOMETHING HERE
    }
    ....
*/

void printRowCount(unsigned int rowCount, bool withTopic);
void refreshMenuDisplay(byte refreshMode);
byte getNavAction();
void startBacklightPWM();
void stepperAttach();
void stepperDetach();
void toRefPoint();
void toMaxPoint();
byte processMenuCommand(byte cmdId);
void homing();
void lcdClear();
void printVersion();
void show2secMessage(const __FlashStringHelper *line1, const __FlashStringHelper *line2, const AppModeValues appM);
void show2secMessage(const char *line1, const char *line2, const AppModeValues appM);
#ifdef DEBUG_POSITION
void debugReportSteps();
#endif

// ------------------------------------------------------------------------
void stepperAttach()
{
  myStepper.attach(stepPin, dirPin);
  myStepper.attachEnable(enaPin, enaDelay, signalLevel); // Enable Pin aktivieren ( signalLevel=aktiv )
  myStepper.setSpeed(homeSpeed);
  myStepper.setRampLen(rampLen); // Rampenlänge 100 Steps bei 20U/min
  digitalWrite(enaPin, enaLevel);
  delay(enaDelay);
  stepperAttached = 1;
}

// ------------------------------------------------------------------------
void stepperDetach()
{
  myStepper.detach();
  digitalWrite(enaPin, LOW);
  stepperAttached = 0;
}

// ------------------------------------------------------------------------
// Move stepper to home position, backup and return
void toRefPoint()
{
  // Run stepper to home endpoint and zero position
  DBG_PRINT(F("Homing"));

  // move fast to endpoint...
  if (digitalRead(homePin) != signalLevel)
  {
    // ... but only if stepper is not already there
    myStepper.setSpeedSteps(fastSpeedSteps, rampLen);
    myStepper.rotate(STEP_CW);
    while (digitalRead(homePin) != signalLevel)
      ;
  }

  // home endstop reached, stop
  myStepper.stop();
  delay(10); // give stepper driver time to reenable - UNO R4 is too fast :-)!
  // slow backup until endstop releases
  myStepper.setRampLen(0);
  myStepper.setSpeedSteps(slowSpeedSteps);
  myStepper.rotate(STEP_CCW);
  while (digitalRead(homePin) == signalLevel)
    ;

  DBG_PRINTLN(F("Home endpoint reached"));
  myStepper.rotate(0);
  while (myStepper.moving())
    ;
  myStepper.setZero(); // zero stepper pos
  myStepper.setSpeed(operationRPM);
  myStepper.setRampLen((uint16_t)rampLen); // acceleration ramp 100 steps at 20rpm
  DBG_PRINTLN(F("Homeing end"));
}

// ------------------------------------------------------------------------
// Move stepper to max end of pathway
void toMaxPoint()
{
  // Run stepper to home endpoint and zero position
  DBG_PRINTLN(F("Going to max endstop"));
  // move fast to endpoint...
  if (digitalRead(maxPin) != signalLevel)
  {
    // ... but only if stepper is not already there
    myStepper.setSpeedSteps(fastSpeedSteps, rampLen);
    myStepper.rotate(STEP_CCW);
    while (digitalRead(maxPin) != signalLevel)
      ;
  }

  // home endstop reached, stop
  myStepper.stop();
  delay(10); // give stepper driver time to reenable - UNO R4 is too fast :-)!
  // slow backup until endstop releases
  myStepper.setRampLen(0);
  myStepper.setSpeedSteps(slowSpeedSteps);
  myStepper.rotate(STEP_CW);
  while (digitalRead(maxPin) == signalLevel)
    ;

  DBG_PRINT(F("Max endpoint reached at: "));
  DBG_PRINTLN(myStepper.currentPosition());
  myStepper.rotate(0);
  while (myStepper.moving())
    ;
  myStepper.setSpeed(operationRPM);
  myStepper.setRampLen((uint16_t)rampLen);
  stepperMaxPos = myStepper.currentPosition();
  DBG_PRINTLN(F("Maxing finished"));
}

#ifdef DEBUG_POSITION
// ------------------------------------------------------------------------
// report steps debug
void debugReportSteps()
{
  char dbgbuf[250];
  uint32_t interval = 250;
  static uint32_t last = -interval;

  if (millis() - last < interval)
    return;
  last += interval;
  dbgbuf[0] = 0;
  snprintf(dbgbuf, sizeof(dbgbuf), "stepper: %ld, newEncPosition: %ld, posFromEncoder: %ld, posDiff: %ld", myStepper.currentPosition(), newEncPosition, (long)posFromEnc, (myStepper.currentPosition() - posFromEnc));
  DBG_PRINTLN(dbgbuf);
}
#endif

//----------------------------------------------------------------------
// Callback to convert button press to navigation action.
byte getNavAction()
{
  byte navAction = 0;
  byte currentItemHasChildren = Menu1.currentItemHasChildren();

  if (btn == BUTTON_UP_PRESSED || btn == BUTTON_UP_LONG_PRESSED)
    navAction = MENU_ITEM_PREV;
  else if (btn == BUTTON_DOWN_PRESSED || btn == BUTTON_DOWN_LONG_PRESSED)
    navAction = MENU_ITEM_NEXT;
  else if (btn == BUTTON_SELECT_PRESSED || (btn == BUTTON_RIGHT_PRESSED && currentItemHasChildren))
    navAction = MENU_ITEM_SELECT;
  // else if (btn == BUTTON_LEFT_PRESSED) navAction = MENU_BACK;
  return navAction;
}

// Callback to refresh display during menu navigation, using parameter of type enum DisplayRefreshMode.
void refreshMenuDisplay(byte refreshMode)
{
  char nameBuf[LCD_COLS + 1];

  /*
    if (refreshMode == REFRESH_DESCEND || refreshMode == REFRESH_ASCEND)
    {
      byte menuCount = Menu1.getMenuItemCount();

      // uncomment below code to output menus to serial monitor
      if (Menu1.currentMenuHasParent())
      {
        Serial.print("Parent menu: ");
        Serial.println(Menu1.getParentItemName(nameBuf));
      }
      else
      {
        Serial.println("Main menu:");
      }

      for (int i=0; i<menuCount; i++)
      {
        Serial.print(Menu1.getItemName(nameBuf, i));

        if (Menu1.itemHasChildren(i))
        {
          Serial.println("->");
        }
        else
        {
          Serial.println();
        }
      }
    }
  */

  lcd.setCursor(0, 0);
  if (Menu1.currentItemHasChildren())
  {
    rpad(strbuf, Menu1.getCurrentItemName(nameBuf));
    strbuf[LCD_COLS - 1] = 0b01111110; // Display forward arrow if this menu item has children.
    lcd.print(strbuf);
    lcd.setCursor(0, 1);
    lcd.print(rpad(strbuf, EmptyStr)); // Clear config value in display
  }
  else
  {
    byte cmdId;
    rpad(strbuf, Menu1.getCurrentItemName(nameBuf));

    if ((cmdId = Menu1.getCurrentItemCmdId()) == 0)
    {
      strbuf[LCD_COLS - 1] = 0b01111111; // Display back arrow if this menu item ascends to parent.
      lcd.print(strbuf);
      lcd.setCursor(0, 1);
      lcd.print(rpad(strbuf, EmptyStr)); // Clear config value in display.
    }
    else
    {
      lcd.print(strbuf);
      lcd.setCursor(0, 1);
      lcd.print(" ");
      lcd.print(rpad(strbuf, currentConfig.getFormattedStr(cmdId))); // Display config value.
    }
  }
}

//----------------------------------------------------------------------
void printRowCount(unsigned int rowCount, bool withTopic)
{
  char intbuf[4];
  // char tmpbuf[17];
  byte bdPad = 0;

#ifdef DEBUG_DISPLAY
  DBG_PRINTLN("-------");
  DBG_PRINTLN("printRowCount()");
  DBG_PRINT("oldEncPosition: ");
  DBG_PRINTLN(oldEncPosition);
  DBG_PRINT("newEncPosition: ");
  DBG_PRINTLN(newEncPosition);
  DBG_PRINT("rowcount: ");
  DBG_PRINTLN(rowCount);
  DBG_PRINT("currAppM:");
  DBG_PRINTLN(currentAppMode);
  DBG_PRINT("nextAppM:");
  DBG_PRINTLN(nextAppMode);
#endif

  /*
    // acquire direction, but only if stepper is moving
    if (myStepper.moving())
    {
      // carriage going right
      if (newEncPosition < oldEncPosition)
      {
        encDir = STEP_CCW;
      }
      // carriage going left
      if (newEncPosition > oldEncPosition)
      {
        encDir = STEP_CW;
      }
    }
  */
#ifdef DEBUG_DISPLAY
  DBG_PRINT("encDir: ");
  DBG_PRINTLN(encDir);
#endif

  if (withTopic == true)
  {
    lcd.clear();
    lcd.setCursor(0, 0);
    if (currentConfig.cfg.opMode)
    {
      lcd.print(F(MAIN_rtk));
    }
    else
    {
      lcd.print(F(MAIN_rk));
    }
  }

  lcd.setCursor(0, 1);

  inttostr(intbuf, rowCount);
  char tmpbuf[LCD_COLS + 1];

  if (nextAppMode == APP_ALARM)
  {
    strlcpy(tmpbuf, PSTR(MAIN_done), sizeof(tmpbuf));
    rpad(strbuf, tmpbuf);
  }
  else
  {
    if (rowCount == 1)
    {
      strlcpy(tmpbuf, PSTR(MAIN_row), sizeof(tmpbuf));
      fmt(strbuf, 2, intbuf, tmpbuf);
    }
    else
    {
      strlcpy(tmpbuf, PSTR(MAIN_rows), sizeof(tmpbuf));
      fmt(strbuf, 2, intbuf, tmpbuf);
    }
  }

  rpad(strbuf, strbuf); // if strbuf is not padded to full length, one cannot put an arrow at the end
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
void loop()
{

  char sngbuf[longest_tune + 1];

  btn = getButton();

  // button beep
  if (btn && currentConfig.cfg.buttonBeep && currentAppMode != APP_ALARM)
  {
    byte btnFlags = btn & 192;

    if (btnFlags == BUTTON_PRESSED_IND) // if any button pressed.
    {
      tone(alarmPin, NOTE_G5, 100);
    }
  }
  else if (btn) // if any button pressed, but no beep enabled
  {
    // do nothing
    DBG_PRINTLN(F("Button pressed, but no beep enabled"));
  }

  // footswitch installed?
  if (currentAppMode == APP_PRE_CHECK && 0 && digitalRead(footswitchPin) == signalLevel)
  {
    errorState = MISS_FOOT;
  }
  else if (currentAppMode == APP_PRE_CHECK)
  {
    errorState = OK;
    currentAppMode = APP_PGMSTART;
    nextAppMode = APP_PGMSTART;
  }

  // check endstops and sensors
  if (stepperAttached == 1)
  {
    if (myStepper.moving())
    {

      homeBtn.update();
      if (homeBtn.pressed())
      {
        myStepper.stop();
        errorState = HIT_HOME;
        knitContinuous = 0;
        knitRow = 0;
      }

      maxBtn.update();
      if (maxBtn.pressed())
      {
        myStepper.stop();
        errorState = HIT_MAX;
        knitContinuous = 0;
        knitRow = 0;
      }

      if (currentConfig.cfg.yarnsensorMainEnable == true)
      {
        yarnMainSens.update();
        if (yarnMainSens.pressed())
        {
          errPreservedDir = encDir;
          myStepper.stop();
          errorState = HIT_YARN1;
          knitContinuous = 0;
          knitRow = 0;
        }
      }

      if (currentConfig.cfg.yarnsensorSecEnable == true)
      {
        yarnSecSens.update();
        if (yarnSecSens.pressed())
        {
          errPreservedDir = encDir;
          myStepper.stop();
          errorState = HIT_YARN2;
          knitContinuous = 0;
          knitRow = 0;
        }
      }

      if (currentConfig.cfg.overloadsensorEnable == true)
      {
        overloadSens.update();
        if (overloadSens.pressed())
        {
          myStepper.stop();
          errorState = ERR_OVRL;
          knitContinuous = 0;
          knitRow = 0;
        }
      }
    }
  }

  // only proceed if errorState is OK
  if (errorState == OK)
  {

    // reset direction arrow on display if not moving
    if (!currentConfig.cfg.arrowMode)
    {
      if (!myStepper.moving() && arrowShown == 1)
      {
        for (int i = 0; i < 5; i++)
        {
          lcd.setCursor(LCD_COLS - i, 1);
          lcd.print(" ");
        }
        arrowShown = 0;
      }
    }

    // position from encoder, but only query myStepper if attached
    if (stepperAttached == 1)
    {
      // calculated encoder position from stepper steps
      posFromEnc = round((float)newEncPosition * encoderMultiplier);
#ifdef DEBUG_POSITION
      debugReportSteps();
#endif
    }

    // menu branching
    switch (currentAppMode)
    {

    // ----------------------------------
    // program start
    case APP_PGMSTART:
#ifdef DEBUG_APPMODE
      // DBG_PRINTLN("appMode: APP_PGMSTART");
#endif
      initializeButtons();
      if (stepperAttached == 0)
      {
        startupScreen();
      }

      if (btn == BUTTON_SELECT_SHORT_RELEASE)
      {
        homing();
        currentAppMode = APP_DISP_UPD;
        nextAppMode = APP_NORMAL_MODE;
        screenToShow = ROWS_WITH_HEADER;
      }
      break;
    // ----------------------------------
    // normal operation, menu closed
    case APP_NORMAL_MODE:
#ifdef DEBUG_APPMODE
      DBG_PRINTLN("appMode: APP_NORMAL_MODE");
#endif

      if (btn == BUTTON_SELECT_LONG_PRESSED)
      {
        startCarriage();
      }

      if (btn == BUTTON_UP_LONG_PRESSED)
      {
        lcd.clear();
        menuStartTime = millis();
        currentAppMode = APP_MENU_MODE;
        refreshMenuDisplay(REFRESH_DESCEND);
      }

      if (btn == BUTTON_DOWN_LONG_PRESSED)
      {
        currentConfig.cfg.rowCount = 0;
        currentConfig.save();
        currentRowCount = currentConfig.cfg.rowCount;
        currentAppMode = APP_DISP_UPD;
        screenToShow = ROWS_WITH_HEADER;
      }

      if (btn == BUTTON_RIGHT_LONG_PRESSED)
      {
        if (!myStepper.moving())
        {
          screenToShow = ROWS_WITH_HEADER;
          if (currentConfig.cfg.navMode == true) // navMode = maximum
          {
            if (myStepper.currentPosition() > (0 + endstopOffset))
            {
              myStepper.moveTo(0 + endstopOffset);
              show2secMessage(F(MAIN_goingto), F(MAIN_zero), APP_DISP_UPD);
            }
          }
          else // navMode = boundary
          {
            if (myStepper.currentPosition() > (0 + endstopOffset))
            {
              if (currentConfig.cfg.rightBoundary != 0)
              {
                if (myStepper.currentPosition() == currentConfig.cfg.rightBoundary)
                {
                  myStepper.moveTo(0 + endstopOffset);
                  show2secMessage(F(MAIN_goingto), F(MAIN_zero), APP_DISP_UPD);
                }
                else
                {
                  myStepper.moveTo(currentConfig.cfg.rightBoundary);
                  show2secMessage(F(MAIN_goingto), F(MAIN_rbnd), APP_DISP_UPD);
                }
              }
              else
              {
                myStepper.moveTo(0 + endstopOffset);
                show2secMessage(F(MAIN_goingto), F(MAIN_zero), APP_DISP_UPD);
              }
            }
          }
        }
      }

      if (btn == BUTTON_LEFT_LONG_PRESSED)
      {
        if (!myStepper.moving())
        {
          screenToShow = ROWS_WITH_HEADER;
          if (currentConfig.cfg.navMode == true) // navMode = maximum
          {
            if (myStepper.currentPosition() < (stepperMaxPos - endstopOffset))
            {
              myStepper.moveTo(stepperMaxPos - endstopOffset);
              show2secMessage(F(MAIN_goingto), F(MAIN_max), APP_DISP_UPD);
            }
          }
          else // navMode = boundary
          {
            if (myStepper.currentPosition() < (stepperMaxPos - endstopOffset))
            {
              if (currentConfig.cfg.leftBoundary != 0)
              {
                if (myStepper.currentPosition() == currentConfig.cfg.leftBoundary)
                {
                  myStepper.moveTo(stepperMaxPos - endstopOffset);
                  show2secMessage(F(MAIN_goingto), F(MAIN_max), APP_DISP_UPD);
                }
                else
                {
                  myStepper.moveTo(currentConfig.cfg.leftBoundary);
                  show2secMessage(F(MAIN_goingto), F(MAIN_lbnd), APP_DISP_UPD);
                }
              }
              else
              {
                myStepper.moveTo(stepperMaxPos - endstopOffset);
                show2secMessage(F(MAIN_goingto), F(MAIN_max), APP_DISP_UPD);
              }
            }
          }
        }
      }

      if (btn == BUTTON_LEFT_SHORT_RELEASE)
      {
        if (!myStepper.moving())
        {
          if (myStepper.currentPosition() != stepperMaxPos)
          {
            myStepper.move(240);
          }
        }
      }

      if (btn == BUTTON_RIGHT_SHORT_RELEASE)
      {
        if (!myStepper.moving())
        {
          if (myStepper.currentPosition() != 0)
          {
            myStepper.move(-240);
          }
        }
      }

      footswitchBtn.update();
      if (footswitchBtn.pressed())
      {
        fpHit = 1;
      }

      // foot pedal hit?
      if (fpHit == 1)
      {
        if (currentConfig.cfg.footMode)
        {
          if (!myStepper.moving())
          {
            knitRow = 1;
            currentAppMode = APP_CARRIAGE_RUNNING;
          }
        }
        else
        {
          startCarriage();
        }
        fpHit = 0;
      }

      break;

    // ----------------------------------
    // active whenever the carriage moves
    case APP_CARRIAGE_RUNNING:
#ifdef DEBUG_APPMODE
      DBG_PRINTLN("appMode: APP_CARRIAGE_RUNNING");
#endif

      if (knitRow == 1)
      {
        if (!myStepper.moving())
        {
          DBG_PRINT(F("Request to knit 1 row: "));

          if (errPreservedDir != STEP_STOP) // stepper stopped on error
          {
            DBG_PRINT(F("errPreservedDir: "));
            DBG_PRINTLN(errPreservedDir);
            switch (errPreservedDir)
            {
            case STEP_CCW:
              knitRight();
              break;
            case STEP_CW:
              knitLeft();
              break;
            }
          }
          else // normal operation
          {
            // carriage below half => knit to the left
            if (myStepper.currentPosition() < stepperMidPos)
            {
              knitLeft();
            }
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

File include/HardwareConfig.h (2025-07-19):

/*!`
 * \file HardwareConfig.h
 *
 * This file is part of Open Knitting Motor Project OKMP.
 *
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
 *    Original Work Copyright 2024 Holger Pandel
 *    http://pages.open-mind.space/knittingmotor
 */

#ifndef HWCONFIG_H_
#define HWCONFIG_H_

#include <Arduino.h>

// LiquidCrystal display init pins
const byte d0Pin = 4;
const byte d1Pin = 5;
const byte d2Pin = 6;
const byte d3Pin = 7;
const byte rsPin = 8;
const byte enablePin = 9;

// Encoder pins and parameters
const byte rotaA = 2;    // encoder pin A
const byte rotaB = 3;    // encoder pin B
const int encRes = 2400; // encoder resolution

// Stepper pins and parameters
const byte stepPin = 11;          // stepper PUL(SE)
const byte dirPin = 12;           // stepper DIR(ECTION)
const byte enaPin = 13;           // stepper ENA(BLE)
const byte enaLevel = HIGH;       // level to enable stepper
const byte enaDelay = 200;        // DM542T (v4.0) - enable time at least 200ms according manual
const int stepsPerRev = 1600;     // Steps per Revolution ( example with 1/4 microsteps )
const int rampLen = 200;          // stepper acceleration ramp
const int homeSpeed = 1600;        // constant homing speed, regardless of user speed setting
const int bndSetupSpeed = 1000;   // fixed speed for setting boundaries
const int carSpeedMin = 60;       // minimum carriage speed
const int carSpeedMax = 200;      // maximum carriage speed
const int fastSpeedSteps = 20000; // steps per 10sec fast
const int slowSpeedSteps = 1000;  // steps per 10sec slow
const int endstopOffset = 80;     // endstop clearance offset after homing
const int navSteps = 240;         // steps to move on navigation button left/right single press
const int bndSmallSteps = 120;    // steps to move on boundary setup left/right single press
const int bndLargeSteps = 600;    // steps to move on boundary setup left/right press and hold

// Endstop pins and parameters
const byte homePin = A5;     // home endstop
const byte maxPin = A4;      // max endstop
const byte atRefpoint = LOW; // endstop active on ... level

// Signal pins and parameters
const byte footswitchPin = A3; // footswitch
const byte yarnMainPin = A2;   // main yarn sensor pin (SET TO UNUSED PIN NO. IF NOT USED)
const byte yarnSecPin = A1;    // second yarn sensor pin (SET TO UNUSED PIN NO. IF NOT USED)
const byte overloadPin = 1;    // carrier overload sensor pin (SET TO UNUSED PIN NO. IF NOT USED)
const byte alarmPin = 0;       // buzzer pin
const byte signalLevel = HIGH; // switch level

// Box params
const long maxRows = 999; // maximum no. of rows to knit

const float encoderMultiplier = ((float)stepsPerRev / (float)encRes); // encoder to stepper steps transpose value

// const unsigned long swDebounceTime = 20;  // switch debounce time - NOT USED, see ISR (PCINT1_vect){...}

#endif

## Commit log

2024-02-20 Working mockup.
    [KnittingMotorMenu.xml]
2024-02-21 First working release 0.0.1-prod
    [KnittingMotorMenu.xml]
2024-02-21 appMode variables renamed, better interrupt handling
2024-02-21 Operation mode added (auto/manual)
    [KnittingMotorMenu.xml]
2024-02-21 Foot pedal mode / Direction arrow option
    [KnittingMotorMenu.xml]
2024-02-21 More external pin definition
2024-02-22 - Error correction - code and file restructuring - additional screen messages
    [HardwareConfig.h, main.cpp]
2024-02-22 BambuLab 3MF all parts PLA+
    [Knitting_machine_motor.3mf]
2024-02-26 Yarn sensor 1+2, Overload Sensor logic
    [KnittingMotorMenu.xml]
2024-02-27 - added RTTTL alarm tunes - alarm duration removed - overflow and yarn sensor handling
    [Knitting machine motor.3mf, KnittingMotorMenu.xml, Knitting_machine_motor.3mf]
2024-03-01 - Changes not working, somehow box reboots
    [main.cpp]
2024-03-01 Documentation changes
    [Knitting machine motor.3mf, KnittingMotorMenu.xml]
2024-03-02 - Autoversioning - Processing optimized - Yarn sensing (main/Sec) finished
    [Knitting machine motor.3mf, KnittingMotorMenu.xml]
2024-03-08 - extra script mod - docu mod - Config/Lang/RTTTLTunes new const
    [Knitting machine motor.3mf]
2024-03-10 - Problems with endstops solved - Code restructuring
    [HardwareConfig.h, main.cpp]
2024-03-10 - Removed the whole ISR/PCI code. It was causing unstable behaviour regarding the enstop and sensing pins. Now everything is handled by the Bounce2 library in loop(), which is totally stable. - Docu 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
    [HardwareConfig.h, main.cpp]
2024-03-11 Arduino UNO R4 support
2024-03-14 - Add Nav mode for left/right buttons - Show boundary symbol only for boundaries != 0 - Change LCD backlight timing
    [KnittingMotorMenu.xml]
2024-03-14 - missing breal; in APP_PGMSTART -> me idiot! - removed unnecessary variables - added log2file output for debugging via monitor_filters in platform.io - restructured debug output, additional DEBUG_DI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
    Hopefully, direction arrow on screen is now always correct:
    - encDir calculation removed from readEncoder, now in printRowCount,
    - delay 6 milliseconds in knitLeft/Right for the rotary encoder interrupt to update newEncPos
    [main.cpp]
2024-03-15 - correct boundary check on startup - remove unnecessary variable updLcd - set correct carriage speed after editing boundaries - set encDir from knitLeft/Right (reliable!) - correct carriage directio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
    [main.cpp]
2024-04-04 - Missing entries in Lang.h - more build envs in platformio.ini (for CI/CD) - current 3mf
    [Knitting machine motor.3mf]
2024-04-07 Add STL overview
    [Knitting machine motor.3mf, Open knitting motor.3mf]
2024-04-15 Upd parts list; add STLs from Fusion project V96
    [GT2_clip_(2x).stl, M3_std_screw_knob_(2x).stl, M5_std_screw_knob_(2x).stl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]
2024-04-26 - added mover_plate_v2 - updated docu regarding mover plate v2
    [Open knitting motor.3mf, mover_plate_v2.stl]
2024-04-26 Wrong print plate type
    [Open knitting motor.3mf]
2024-04-30 Docu: update wiring.md
2024-04-30 Docu: add hint regarding electrostatic charge
2024-12-05 Unnecessary parts removed
    [Open knitting motor.3mf]
2024-12-05 Better picture for belt tensioner

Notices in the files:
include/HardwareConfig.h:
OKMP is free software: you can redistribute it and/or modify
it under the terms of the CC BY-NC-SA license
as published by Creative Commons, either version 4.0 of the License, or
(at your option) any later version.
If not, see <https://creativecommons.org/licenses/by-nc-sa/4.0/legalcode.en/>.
